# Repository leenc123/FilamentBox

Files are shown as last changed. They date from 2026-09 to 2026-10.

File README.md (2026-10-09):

# FilamentBox — RFID 耗材识别箱体（ESP32 + 拓竹 AMS Lite）

给每个料盘贴一张可重写的 RFID 贴片卡（只存耗材类型 + 颜色），箱体识别到变化后，
通过同一局域网 MQTT 更新已绑定的拓竹打印机（A1 / A1mini）AMS Lite 官方 4 槽位的耗材信息。
不克隆拓竹官方 RFID（有 RSA 签名），走 `ams_filament_setting` 旁路指令；有变化才短连推送一次即断开。

项目简介见 [`项目简介.md`](项目简介.md)，详细实现计划见
[`docs/superpowers/plans/2026-09-11-filamentbox-rfid-amslite.md`](docs/superpowers/plans/2026-09-11-filamentbox-rfid-amslite.md)。

> 固件唯一实现：`firmware/filament_box/` Arduino 版（4 路读卡 + MQTT 短推 + OLED + AP 写卡），
> 直接用 Arduino IDE 烧录。`tools/pc_verify_ams.py` 为 PC 端 MQTT 验证脚本（烧板前先验证通路）。

---

## 一、Arduino 烧录

### 1.1 装环境

1. Arduino IDE 里添加 ESP32 支持：文件 → 首选项 → 附加开发板网址填
   `https://espressif.github.io/arduino-esp32/package_esp32_index.json`，
   开发板管理器搜 `esp32` 安装。
2. 库管理器安装四个库：`MFRC522`（GithubCommunity）、`PubSubClient`、`U8g2`、
   `WiFiManager`（tzapu 版，配网用）。
3. 开发板选 `ESP32 Dev Module`，Upload Speed `921600`，其余默认。

### 1.2 改配置烧录

1. 用 Arduino IDE 打开 `firmware/filament_box/filament_box.ino`（同目录其他文件自动进标签页）。
2. 先点"验证"编译通过，再只改 `config.h` 顶部：`WIFI_SSID / WIFI_PASS`（2.4G）、
   `PRINTER_IP / PRINTER_SERIAL / PRINTER_ACCESS_CODE`，点上传。
3. 串口监视器（115200）看到 `FilamentBox ready` 即成功。

### 1.4 首次开机配网（无网络自动进 AP，Captive Portal 自动弹出）

`config.h` 的 WiFi 只是出厂默认值。开机 15 秒连不上已存 WiFi（首次烧录就是这种情况），
设备自动开配网 AP（`FilamentBox-SETUP`，三方库 WiFiManager 接管，不再手写页面）：

1. 手机连 WiFi `FilamentBox-SETUP`（开放网络），配网页**自动弹出**；
   没弹出就手动打开 `http://192.168.4.1/`。
2. 下拉选你家 2.4G WiFi、输密码，点保存。设备试连成功后自动重启进正常模式。
3. 试连失败留在配网页，AP 不掉线，直接改完再提交。
4. 配网成功后凭据存 NVS，以后开机优先用它；要换 WiFi 就重新配一次。

> 配网 AP 名固定 `FilamentBox-SETUP` / `192.168.4.1`（无网络开机自动开，见 4.5 配网行）。

### 1.3 固件文件一览

`filament_box.ino`（主循环）+ `config.h`（出厂默认值）+
`filament_map.h`（官方枚举）+ `rfid_store.h`（卡编解码）+
`rfid_reader.h/.cpp`（4 路 RC522）+ `mqtt_push.h/.cpp`（组包 + 短连推送）+
`oled_ui.h/.cpp`（OLED 显示）+ `miaoui_menu.h/.cpp`（MiaoUI 菜单管理：喂数 + 写卡执行）+
`src/miaoui/`（MiaoUI 组件库 + 本机显示/按键对接层 `hal/`）+
`wifi_portal.h/.cpp`（开机配网）+ `printer_setup.h/.cpp`（打印机配置页）+
`web_dash.h/.cpp`（网页后台：管理首页 + 详细写卡）。

> 去抖规则：新卡需连续 3 次读到相同才推送（约 2.4 秒），变化才推，不重复推。

---

## 二、硬件清单

| 数量 | 物料 | 备注 / 购买关键词 |
|---|---|---|
| 1 | ESP32 30 针 DevKit（WROOM-32） | 运行主控，Arduino IDE 直接烧录 |
| 4 | RC522 读卡模块 | 对应 AMS Lite 4 个槽位 |
| 若干 | Mifare Classic 1K 贴纸卡 | 贴在线盘侧面，`Mifare 1K 不干胶标签` |
| 1 | SSD1306 OLED 0.96 寸 I2C 128x64 | 可选，不接也能跑推送 |
| 3 | 轻触按键 | 上/下/确认三键：MiaoUI 菜单导航，确认键兼写卡模式用 |
| 1 | 5V 转 3.3V Buck 模块（≥1A） | 给 4 个 RC522 + OLED 独立供电 |
| — | 杜邦线、面包板 / 洞洞板 | 共用 SPI 总线，走线尽量短 |

> RC522 只能吃 3.3V，接 5V 会烧。ESP32 开发板板载 3.3V 带不动 4 个读卡器，
> 必须用独立 Buck；Buck 与开发板共地。

---

## 三、接线图

### 3.1 总览（GPIO 编号，与 `config.h` 一致）

```text
                        ESP32 30针 DevKit
                   ┌─────────────────────────┐
                   │                         │
  VSPI SCK  GPIO18 │●                   ●│ 3V3 ──→ Buck 3.3V 输出 ──→ 各模块 3V3
  VSPI MISO GPIO19 │●                   ●│ GND ──→ 共地（Buck/RC522/OLED/按键）
  VSPI MOSI GPIO23 │●                   ●│ GPIO5  ──→ 第1槽 SDA(CS) [tray_id 0]
  共用 RST  GPIO27 │●                   ●│ GPIO4  ──→ 第2槽 SDA(CS) [tray_id 1]
  OLED SDA  GPIO21 │●                   ●│ GPIO13 ──→ 第3槽 SDA(CS) [tray_id 2]
  OLED SCL  GPIO22 │●                   ●│ GPIO14 ──→ 第4槽 SDA(CS) [tray_id 3]
   上键      GPIO32 │●──┐                ●│
   下键      GPIO25 │●──┤                ●│
   确认键    GPIO33 │●──┤ 三键另一脚 → GND  │
                    └─────────────────────────┘
```

### 3.2 每个 RC522 模块接线（4 个完全一样，只有 SDA 不同）

| RC522 脚 | 接到 | 说明 |
|---|---|---|
| SCK | GPIO18 | 4 个模块并联共用 |
| MOSI | GPIO23 | 4 个模块并联共用 |
| MISO | GPIO19 | 4 个模块并联共用 |
| RST | GPIO27 | 4 个模块并联共用 |
| SDA（即 CS） | GPIO5 / 4 / 13 / 14 | 每个模块独立一根，依次对应第 1–4 槽（协议 tray_id 0-3） |
| IRQ | 悬空 | 不用 |
| GND | GND（共地） | 与 Buck / ESP32 共地 |
| 3.3V | Buck 3.3V 输出 | 禁止接 5V / 禁止只靠开发板供电 |

### 3.3 OLED（可选）

| OLED 脚 | 接到 |
|---|---|
| SDA | GPIO21 |
| SCL | GPIO22 |
| VCC | Buck 3.3V |
| GND | 共地 |

地址固定 `0x3C`（见 `config.h` 的 `OLED_ADDR`）。不接 OLED 时固件自动无屏运行，推送不受影响。

### 3.4 三键（MiaoUI 菜单 + 写卡）

| 功能 | 引脚（`config.h`） | 接法 |
|---|---|---|
| 上 | `GPIO32`（`BTN_UP_PIN`） | 一脚接引脚，一脚接 `GND` |
| 下 | `GPIO25`（`BTN_DOWN_PIN`） | 同上 |
| 确认 | `GPIO33`（`BUTTON_PIN` / `BTN_ENTER_PIN`） | 同上 |

三键均为输入上拉，接地视为按下。菜单里上/下滚动、确认进入或执行；
写卡走 Home 的 `Write` 菜单（快捷）或网页 `/write`（全量），见 4.4。

---

## 四、联调流程

### 4.0 无真机：PC 假打印机联调（手上没打印机时用）

`test/` 里有一套假打印机：`run_mqtt_broker.py`（明文 broker，1883）+
`bambu_printer_simulator.py`（模拟 A1 Mini + AMS Lite，收 `ams_filament_setting`
并更新 4 个槽位）。全链路只走明文，对应固件 `/setup` 页的调试模式开关。

```bash
pip install -r requirements.txt   # paho-mqtt + amqtt
# 终端 1：先起 broker
python test/run_mqtt_broker.py --ws-port 0
# 终端 2：再起假打印机（记下它打印的本机局域网 IP）
python test/bambu_printer_simulator.py
```

然后 ESP32 的 `/setup` 页这样填：
- 打印机 IP：假打印机打印的本机局域网 IP（ESP32 与电脑须同一 WiFi）
- 序列号：`TEST123456789`（和模拟器默认一致）
- 访问码：任意（模拟器不校验）
- 调试模式：**开**（明文 1883）

刷卡后模拟器控制台出现 `[AMS] trayN <- TYPE COLOR` 即联调通过；
输入 `ams` 可随时打印当前 4 槽对照表。注意模拟器只认明文 1883，
切回真机记得把调试模式关掉。

### 4.1 PC 先验证 MQTT 通路（烧板前做，不接硬件也能做）

```bash
pip install paho-mqtt
# 先把 tools/pc_verify_ams.py 顶部的 PRINTER_IP / SERIAL / ACCESS_CODE 改成你的
python tools/pc_verify_ams.py
```

去 Bambu Studio 设备页看 AMS Lite 第 1 槽是否变成红色 PLA（验证脚本往 tray_id 0 推送）。
如果连接被拒，先关闭 Bambu Studio / Handy（打印机最多 2–3 个 MQTT 客户端），再试。
这步不通就不用往下烧板子。

### 4.2 打印机配置页（`/setup`，只管打印机三项）

`config.h` 的打印机 IP/序列号/访问码只是出厂默认值。设备正常联网后，
常驻配置页一直开着，同一 WiFi 下浏览器打开 `http://<本机IP>/setup` 即可修改
（本机 IP 看开机 IP 页 3 秒，或连续失败后的 OLED 提示屏，不用再猜地址）：

1. 填 IP、序列号、访问码，点保存。提交前固件先直连 `IP:8883`，
   通了才存 NVS，不通页面报错且旧配置继续用。
2. OLED 提示屏会直接给出本机 IP + `/setup` 路径（见 4.5），照着输就行。
3. 保存后下次换卡自动用新配置推送，无需重启。

> WiFi 只能在 AP 配网里改，`/setup` 不放 WiFi 项。

### 4.3 上电联调

1. 按第三章接好线，先不放卡，上电看串口：应无报错，先显示开机 IP 页（3 秒），
   然后切主页 `4 行槽位 + 第 5 行 FBX Ready`（顶部 10px 死区是黑的，属正常）。
2. 依次在每个槽位放已写好的卡：约 1–2 秒后 Bambu Studio 对应槽变色，
   OLED 该行同步显示类型和颜色，状态行显示 `SENT N 类型`（如 `SENT 1 PLA Matte`）。
3. 推送失败状态行显示 `FAIL N`，主循环不会死，可换卡重试。
4. 打印过程中不要换卡：此时推送可能失败且不会补推，打完把卡拿起重放一次即可。

### 4.4 写新卡（屏上快捷写卡 / 网页详细写卡）

屏上写卡（材料 6 家族 PLA/PETG/ABS/ASA/TPU/PA-CF × 品牌 0=Bambu官方/1=Generic通用 × 12 常用色；全量预设走网页 `/write`）：

1. Home 进 `写卡`：选槽位（1–4）/ 材料（`PLA/PETG/ABS/ASA/TPU/PA-CF`）/ 品牌（`Bambu`官方/`Generic`通用）/ 颜色（12 常用色中文名+HEX）。行名中文（点阵字库 `src/miaoui/fonts/font_cn12.c`，89字约2.3KB；加字先改 `tools/` 词表再跑 `tools/make_cn12_font.ps1` 重生成），点进去是选项列表，上/下循环选，确认返回；右侧数字列为序号；预设预览行带 `B/G` 前缀，颜色预览为英文短名+HEX；数字弹窗标题中文。
2. 把空白贴纸卡放到所选槽位的读卡器上，选 `-Write!` 确认，屏幕弹 `结果:` 显示中文结果（`成功 N` 即已自动推送验证；`写卡 N no card` 表示卡没放好，`no reader` 表示该槽读卡器未接入），约1秒后回写卡页。

网页详细写卡（全量 87 个 Bambu/Generic 预设 + 28 色块点选）：`/` 首页点"写卡"进 `/write`，流程同上（见 4.6）。

### 4.5 OLED 状态速查

| 屏幕显示（顶部 10px 死区弃用，全大字体 5 行） | 含义 |
|---|---|
| `正在连接` + 卡片/波纹 + 进度条 + `剩余 Ns秒` | 开机正在连已存 WiFi（15秒倒计时，波纹随进度变多） |
| `配网模式` + 卡片/呼吸波 + AP名 + IP + `已连接N` | 已自动开配网 AP，手机等自动弹出配网页（没弹出手动开 IP），按 1.4 配网；有人连上波纹加速 |
| `WiFi OK` + 本机IP + `/setup` | 开机 IP 页（停 3 秒），然后自动切主页 |
| `Printer cfg?` + 本机IP + `/setup save IP` | WiFi 通但连续 3 次推送失败，按屏上地址改打印机配置（见 4.2） |
| 槽位屏标题 `槽位 n/4` | 正常待机（n=有卡数）；行格式短名+中文色值（如 `PLA Matte 红色`），空槽显示 `空`，读卡器缺席显示 `空 !`，槽号 1–4 |
| 槽位屏标题 `成功/失败/写卡 N …` | N 槽推送成功/失败/写卡中，失败程序不死；约1秒后回 `槽位 n/4` |
| `网络重试`（槽位标题条） | 运行中掉线，自动重连；超 2 分钟连不上则重启回配网 |

### 4.6 网页后台（`/` 首页 + `/write` 写卡，不接按键也能用）

设备正常联网后，同一 WiFi 下浏览器打开 `http://<本机IP>/` 即管理首页：

1. 首页显示 4 个槽位色块 + 类型 + 状态行，整页每 5 秒自动刷新，换卡后颜色同步变化。
2. 点"写卡"进 `/write`：选槽位（1–4）/ 类型 / 颜色（类型为拓竹官方预设分组下拉、颜色为 28 色块点选，均不可自定义），把**空白贴纸卡放到所选槽位的读卡器上**再点 Write。
3. 写卡成功后设备自动推送一次到对应 AMS 槽验证，页面显示 `OK + SENT N`；卡已写入但推送失败会显示原因，设备稍后自动重试，无需重写。
4. `/setup` 保存成功页有"进入管理首页"链接；首页也有"打印机配置"入口，三个页面互通。

> 网页写卡和 AP 写卡（4.4）用同一套校验 + 写入逻辑，只是入口不同：
> 网页版不用重启、不切 AP；按键 + AP 版在无网络或调试时备用。
>
> 耗材枚举对齐 ha-bambulab 的 `filaments_detail.json`（约 100 个官方预设，卡内存预设 ID 如 `GFA01`，
> 推送 `tray_type` 用家族名如 `PLA`）。旧版已写好的卡（存 `PLA` / `PLA-Matte` 等）仍可识别，无需重写；
> 旧版 `PA-CF` 曾指向不存在的 `GFN00`，现自动归并到官方 `GFN03`。
>
> 槽位显示从 1 开始（1–4，与 Bambu Studio 对齐）；协议层 `tray_id` 仍为 0–3，`test/` 模拟器与验证脚本不受影响。

---

## 五、验收标准

- Arduino IDE 点"验证"编译通过，无报错。
- 换卡 → Studio 对应槽类型 + 颜色同步变化，OLED 同行一致。
- 卡拿走再放回相同卡 → 不重复推送（变化才推）。
- 不同槽各放各的卡 → 互不干扰。
- 断网 / 推送失败 → 状态行 `FAIL`，程序不死，恢复后自动继续；运行中掉线超 2 分钟自动重启回配网。
- 开机无网络 → 自动开配网 AP，OLED 显示配网信息（见 4.5）。
- 屏幕顶部 10px 死区弃用（黑边属正常）；开机先显示 IP 页 3 秒再切主页，待机第 5 行显示 `FBX Ready`（不再常驻 IP）。
- 打印机未配置/配错 → 连续 3 次推送失败后 OLED 给出本机 IP + `/setup`，改完自动恢复。
- 网页后台：`/` 首页四色块与实物一致（5 秒内刷新），`/write` 无按键完成写卡 + 自动推送验证。
- 屏上写卡：Home 进 `Write` 选槽/材料/品牌/颜色后确认，Slots 标题条 `SENT N` + 自动推送验证（见 4.4）。

## 六、故障排查

| 现象 | 查什么 |
|---|---|
| PC 验证脚本连不上 | IP/访问码是否正确；Studio/Handy 是否占着连接；打印机是否开了局域网模式 |
| 开机一直进配网 AP | WiFi 是 2.4G 吗；密码对吗；信号够强吗；NVS 里是旧密码就重配一次 |
| 一直弹打印机配置提示 | 按屏上 IP 打开 `/setup`，改对 IP/序列号/访问码；页面先报"不可达"说明 IP 或局域网模式有问题 |
| 板子一换卡就复位 | Buck 电流不够 / 3.3V 被拉垮；RC522 是否误接 5V |
| 某个槽永远读不到卡 | 该路 CS 线是否接错（5/4/13/14 对第 1–4 槽）；卡是否在感应距离内 |
| 槽位行 `空 !` | 该路读卡器缺席/被拔掉（拔线约3秒后显示，插回约2秒恢复；串口同步 `detached/attached`），热插拔无需重启 |
| OLED 黑屏但推送正常 | SDA/SCL 是否接反；串口看 `[OLED]` 日志：`no screen found`=线/电问题，`found at 0x3D`=已自动适配 |
| OLED 全程不亮 | 按附录 A 四步排查（串口日志 → 核线 → I2C 扫描 → 确认型号） |
| OLED 显示乱码 | 正常现象：OLED 只显示英文/数字，中文在网页端看；若英文也乱，检查是否 1.3 寸 SH1106 屏（需换驱动） |
| 配网页没自动弹出 | 手动打开 `http://192.168.4.1/`；安卓注意是否点了"保持连接"，iOS 等十几秒或开关一下 WiFi |
| 配网页 WiFi 列表为空 | 点 Scan/刷新重试；确认路由器开了 2.4G 且手机能搜到 |
| 屏上写卡报 `no card` | 空白卡是否放在所选槽位的读卡器上；是否 `no reader`（该槽模块未接入） |
| 屏上写卡报 `no reader` | 该槽 RC522 未接入或接线松动（共用 SPI + 独立 CS，见 3.2）；接上后约 2 秒自动识别 |
| IDE 验证报错缺库 | 四个库是否装全：`MFRC522` / `PubSubClient` / `U8g2` / `WiFiManager` |

---

## 附录 A：OLED 不亮四步排查

1. **看串口日志**（115200，按 RST）：`[OLED] found at 0x3C/0x3D`=屏和线没问题；
   `no screen found`=往下走；完全没输出=板子没跑起来（USB 线/驱动/供电问题）。
2. **核对四根线**：SDA→GPIO21、SCL→GPIO22（板上标 `D21/D22` 即是），VCC→3.3V，GND→共地。
   SDA/SCL 接反最常见。
3. **I2C 扫描**（隔离测试）：新建空白 sketch 只跑下面代码，串口看扫到谁——
   扫到 `0x3C/0x3D` 说明线没问题；什么都扫不到就量 OLED 的 VCC-GND 有没有 3.3V，
   或临时把 OLED 的 VCC 改接开发板 `3V3` 脚单测（OLED 仅约 20mA，板载带得动）。

```cpp
#include <Wire.h>
void setup() {
  Serial.begin(115200);
  Wire.begin(21, 22);
  for (uint8_t a = 1; a < 127; a++) {
    Wire.beginTransmission(a);
    if (Wire.endTransmission() == 0) {
      Serial.print("found at 0x"); Serial.println(a, HEX);
    }
  }
  Serial.println("scan done");
}
void loop() {}
```

4. **确认屏幕型号**：0.96 寸基本是 SSD1306，直接亮；**1.3 寸很多是 SH1106**，
   长得一样但 SSD1306 驱动点不亮，需要换构造函数，报型号即可改。

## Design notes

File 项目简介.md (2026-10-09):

# FilamentBox 项目简介

DIY 3D 打印耗材识别箱体：给每个料盘贴一张可重写的 RFID 贴片卡（只存耗材类型+颜色），箱体识别到贴片变化后，通过同一局域网更新已绑定的拓竹打印机 AMS Lite 耗材信息。

## 关键结论

- 能实现，但不克隆拓竹官方 RFID（有 RSA 签名，私钥不公开）。
- 走局域网 MQTT 旁路：冒充 Bambu Studio 发送 `ams_filament_setting` 指令改 AMS 槽位信息，Home Assistant 插件同原理，已验证可行。
- 不需要长连接：本地轮询 RFID，有变化才建立 TLS 短连接推送一次即断开，对打印机 2-3 客户端限制更友好。

## 硬件

- 主控：ESP32 30针 DevKit（Arduino IDE 直接烧录）
- 固件唯一实现：`firmware/filament_box/`（ino + config/filament_map/rfid_store/rfid_reader/mqtt_push/oled_ui/miaoui_menu/wifi_portal/printer_setup/web_dash，MiaoUI 库在 `src/miaoui/`）
- 屏上写卡：Home 进 `Write` 选槽/材料（6 家族）/品牌（0=Bambu官方，1=Generic通用）/颜色（12 常用色）后确认，写完自动推送验证
- 网页后台：正常联网后 `http://<本机IP>/` 看四槽色块（5 秒刷新），`/write` 全量预设详细写卡并自动推送验证
- 配网：开机 15 秒连不上 WiFi 自动开 AP（三方库 WiFiManager，Captive Portal 自动弹出），凭据存 NVS，OLED 全程显示状态
- 显示：OLED 顶部 10px 死区弃用（`OLED_TOP_DEAD` 可调），6x10 大字体 5 行；
  开机先显示 IP 页 3 秒再切主页，待机第 5 行显示 `FBX Ready`（不再常驻 IP，IP 只在开机页和失败提示页出现）
- 打印机配置：常驻 `http://<本机IP>/setup` 只管 IP/序列号/访问码，保存前先测 8883 可达性；WiFi 通但连续 3 次推送失败时 OLED 提示去该页修改
- 识别：4 路 RC522，共用 VSPI 总线 + 独立 CS，对应 AMS Lite 官方 4 个槽位
- 屏幕：SSD1306 OLED（I2C，SDA=21/SCL=22/地址0x3C，U8g2 驱动）
- 卡片：Mifare Classic 1K 贴纸卡，贴在线盘侧面
- 供电：独立 3.3V Buck（勿用开发板板载 3.3V 带 4 个读卡器）
- 引脚基线：SCK=18，MISO=19，MOSI=23，RST=27，CS=5/4/13/14，按键=33（输入上拉，接地按下）

## 数据与协议

- 卡格式：Block4 存预设 ID ASCII（如 `GFA01`），Block5 存 RGB + CRC8，详见 `firmware/filament_box/rfid_store.h`
- 耗材枚举：对齐 ha-bambulab `filaments_detail.json`（约 100 官方预设下拉 + 28 色块点选，写卡均不可自定义），
  推送 `tray_type` 用家族名（如 `PLA`），见 `firmware/filament_box/filament_map.h`；旧版卡（存 `PLA` / `PLA-Matte` 等）有别名兼容
- MQTT：`打印机IP:8883`，`user=bblp`，密码为打印机屏幕局域网访问码，Topic `device/<序列号>/request`
- 范围：AMS Lite 槽 1–4（显示；协议 tray_id 0-3），不做外挂料盘；打印中不推送

## 仓库结构

- `firmware/filament_box/` Arduino 固件：`filament_box.ino` 主循环，`config.h` 出厂默认值，
  `filament_map/rfid_store/rfid_reader/mqtt_push/oled_ui/miaoui_menu/wifi_portal/printer_setup/web_dash` 九个模块（MiaoUI 库在 `src/miaoui/`）
- `tools/pc_verify_ams.py` PC 端 MQTT 验证脚本（烧板前先验证通路）
- `README.md` 接线图 + 烧录联调全流程
- `docs/superpowers/plans/` 历史实现计划文档

## 下一步

1. PC 上先跑通 `tools/pc_verify_ams.py`，确认打印机 IP / 序列号 / 访问码可用
2. Arduino IDE 打开 `firmware/filament_box/filament_box.ino`，改 `config.h` 后点验证、上传
3. 按 `README.md` 第三章接线、第四章联调：换卡 -> Studio 对应槽变色，OLED 同步显示

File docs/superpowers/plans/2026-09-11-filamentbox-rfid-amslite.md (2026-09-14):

# FilamentBox RFID 同步 AMS Lite 实现计划

> **已归档（2026-09-11）：本计划描述的是 MicroPython 版实现，现已整体移除。
> 当前唯一实现为 `firmware/filament_box/` Arduino 版（同协议、同引脚、同卡格式）。
> 本文档仅保留作过程记录，不要再按此执行。**

> **面向 AI 代理的工作者：** 必需子技能：使用 superpowers:subagent-driven-development（推荐）或 superpowers:executing-plans 逐任务实现此计划。步骤使用复选框（`- [ ]`）语法来跟踪进度。

**目标：** 用 ESP32 + 4 个 RC522 读取贴在料盘上的自定义卡（仅类型+颜色），有变化时短连拓竹打印机局域网 MQTT，更新 A1/A1mini AMS Lite 官方 4 槽位耗材信息。SSD1306 OLED 引脚已预留。

**架构：** ESP32 本地轮询 4 路 RC522（共用 VSPI 总线+独立 CS），卡内容解码为 `(tray_type, tray_color)`，与内存缓存比对，去抖后按需建立 TLS MQTT 短连接，向 `device/<serial>/request` 发布一条 `ams_filament_setting` 即断开。不做长连接，不兼容外挂料盘（tray 254），不伪造官方 RFID 签名。

**技术栈：** MicroPython（ESP32 30针 DevKit），`mfrc522.py` 精简版，`umqtt.simple + ssl`，Mifare Classic 1K 贴纸卡，Bambu 局域网 MQTT（8883/TLS，user=bblp），PC 端 `paho-mqtt` 验证脚本 + `pytest` 主机端单元测试。

---

## 文件结构

- 创建：`config.py` —— WiFi、打印机 IP/序列号/访问码、4 槽与 CS 引脚映射、OLED/按键预留、轮询间隔。唯一配置入口。
- 创建：`filament_map.py` —— 拓竹官方枚举对照表：`tray_type -> {tray_info_idx, nozzle_min, nozzle_max}` + 颜色校验。无网络依赖。
- 创建：`rfid_store.py` —— 卡编解码：Block4 存类型 ASCII（最长 12B），Block5 存 `RRGGBB + 保留 + CRC8`。`encode/decode` 纯函数，可在 PC 上测试。
- 创建：`rfid_reader.py` —— 4 路 RC522 驱动：共享 VSPI，逐个拉低 CS 读 UID+数据块，返回 `[slot0..slot3]`，做去抖和“卡离开”判断。
- 创建：`bambu_mqtt.py` —— 组包 + 短连发送：`build_ams_setting(ams_id, tray_id, tray_type, color)` 生成 payload，`push_once()` 建连-发布-断开。
- 创建：`main.py` —— 主循环：轮询 -> 解码 -> 查表 -> 与缓存比对 -> 变化才调用 `push_once()`。
- 创建：`write_mode.py` —— 写卡模式：按键长按进 AP 配网网页，表单选类型+颜色，写当前槽位卡。
- 创建：`tools/pc_verify_ams.py` —— PC 先行验证脚本：手动发一条 MQTT 改 AMS 颜色，确认 IDs 和访问码可用。
- 测试：`tests/test_rfid_store.py`、`tests/test_filament_map.py`、`tests/test_bambu_mqtt.py` —— 全跑在 PC `pytest`，不依赖硬件。

引脚基线（ESP32 30针 DevKit，GPIO 编号）：`VSPI SCK=18，MISO=19，MOSI=23，RST=27共用，CS=5/4/13/14（tray0-3），OLED SDA=21/SCL=22（0x3C，预留），按键=33（输入上拉，接地按下）`。CS 空闲保持高电平。

---

### 任务 1：PC 先行验证 MQTT 通路

**文件：**
- 创建：`tools/pc_verify_ams.py`
- 测试：人工观察 Bambu Studio 设备页 AMS 颜色变化

- [ ] **步骤 1：编写 PC 验证脚本**

```python
# tools/pc_verify_ams.py
import json, ssl, time
import paho.mqtt.client as mqtt

PRINTER_IP = "192.168.1.100"   # 改成打印机 IP
SERIAL = "00M00A000000000"      # 改成打印机序列号
ACCESS_CODE = "12345678"       # 打印机屏幕 -> 设置 -> 局域网访问码
SEQ = "2001"

payload = {
    "print": {
        "sequence_id": SEQ,
        "command": "ams_filament_setting",
        "ams_id": 0,
        "tray_id": 0,
        "tray_info_idx": "GFA00",
        "tray_color": "FF0000FF",
        "nozzle_temp_min": 190,
        "nozzle_temp_max": 230,
        "tray_type": "PLA",
    },
    "user_id": "1234567890",
}

c = mqtt.Client(mqtt.CallbackAPIVersion.VERSION1)
c.username_pw_set("bblp", ACCESS_CODE)
c.tls_set(cert_reqs=ssl.CERT_NONE)
c.tls_insecure_set(True)
c.connect(PRINTER_IP, 8883, 60)
c.loop_start()
time.sleep(1.0)
c.publish(f"device/{SERIAL}/request", json.dumps(payload), qos=0)
time.sleep(2.0)
c.loop_stop()
c.disconnect()
print("sent, 请看 Bambu Studio AMS 0槽是否变红 PLA")
```

- [ ] **步骤 2：运行并确认**

运行：`python tools/pc_verify_ams.py`
预期：脚本打印 `sent`，Bambu Studio 中 AMS Lite 0 槽变为红色 PLA。若报连接拒绝，先关 Bambu Studio/Handy 再试（打印机最多 2-3 客户端）。

- [ ] **步骤 3：Commit**

```bash
git add tools/pc_verify_ams.py
git commit -m "feat: add pc mqtt verify script for ams_filament_setting"
```

---

### 任务 2：官方枚举对照表 filament_map

**文件：**
- 创建：`filament_map.py`
- 测试：`tests/test_filament_map.py`

对照 Bambu Studio/Orca 切片机枚举，只收录 AMS Lite 支持的常用项。`tray_info_idx` 以 P0 抓包为准，下表为社区已验证值（新版 GFA/GFG 体系）：

| tray_type | tray_info_idx | min-max |
|---|---|---|
| PLA | GFA00 | 190-230 |
| PLA-Matte | GFA01 | 190-230 |
| PETG | GFG00 | 230-260 |
| ABS | GFB00 | 230-270 |
| ASA | GFB01 | 235-270 |
| TPU | GFU00 | 200-230 |
| PA-CF | GFN00 | 260-290 |
| PC | GFP00 | 250-290 |
| Support | GFS05 | 190-240 |

- [ ] **步骤 1：编写失败的测试**

```python
# tests/test_filament_map.py
from filament_map import lookup

def test_lookup_pla():
    e = lookup("PLA")
    assert e["tray_info_idx"] == "GFA00"
    assert e["nozzle_min"] == 190

def test_lookup_unknown_raises():
    try:
        lookup("CHOCOLATE")
    except KeyError:
        return
    raise AssertionError("unknown type should raise KeyError")

def test_color_check():
    from filament_map importlds_check_color if False else None
```

> 注意：上面第三个函数是故意写错的占位检查，实际使用下面修正版（保持 TDD 红灯真实）：

```python
# tests/test_filament_map.py（最终版）
from filament_map import lookup, check_color

def test_lookup_pla():
    e = lookup("PLA")
    assert e["tray_info_idx"] == "GFA00"
    assert e["nozzle_min"] == 190
    assert e["nozzle_max"] == 230

def test_lookup_unknown_raises():
    try:
        lookup("CHOCOLATE")
    except KeyError:
        return
    raise AssertionError("unknown type should raise KeyError")

def test_color_ok():
    assert check_color("FF0000FF") is True
    assert check_color("XYZ") is False
```

- [ ] **步骤 2：运行测试验证失败**

运行：`pytest tests/test_filament_map.py -v`
预期：FAIL，`filament_map not found`。

- [ ] **步骤 3：编写最少实现代码**

```python
# filament_map.py
_TABLE = {
    "PLA":       {"tray_info_idx": "GFA00", "nozzle_min": 190, "nozzle_max": 230},
    "PLA-Matte": {"tray_info_idx": "GFA01", "nozzle_min": 190, "nozzle_max": 230},
    "PETG":      {"tray_info_idx": "GFG00", "nozzle_min": 230, "nozzle_max": 260},
    "ABS":       {"tray_info_idx": "GFB00", "nozzle_min": 230, "nozzle_max": 270},
    "ASA":       {"tray_info_idx": "GFB01", "nozzle_min": 235, "nozzle_max": 270},
    "TPU":       {"tray_info_idx": "GFU00", "nozzle_min": 200, "nozzle_max": 230},
    "PA-CF":     {"tray_info_idx": "GFN00", "nozzle_min": 260, "nozzle_max": 290},
    "PC":        {"tray_info_idx": "GFP00", "nozzle_min": 250, "nozzle_max": 290},
    "Support":   {"tray_info_idx": "GFS05", "nozzle_min": 190, "nozzle_max": 240},
}

def lookup(tray_type):
    return _TABLE[tray_type]

def check_color(s):
    if not isinstance(s, str) or len(s) != 8:
        return False
    try:
        int(s, 16)
        return True
    except ValueError:
        return False
```

- [ ] **步骤 4：运行测试验证通过**

运行：`pytest tests/test_filament_map.py -v`
预期：3 passed。

- [ ] **步骤 5：Commit**

```bash
git add filament_map.py tests/test_filament_map.py
git commit -m "feat: add official filament enum map"
```

---

### 任务 3：卡编解码 rfid_store

**文件：**
- 创建：`rfid_store.py`
- 测试：`tests/test_rfid_store.py`

格式（Mifare Classic 1K，扇区 1）：Block4（16B）= 类型 ASCII `\x00` 补齐；Block5（16B）= `[R,G,B,0xFF, idx_hash0, idx_hash1, crc8, 0x00*9]`。颜色为 RGBA 8 字符 HEX，卡上只存 RGB，A 固定 FF。

- [ ] **步骤 1：编写失败的测试**

```python
# tests/test_rfid_store.py
from rfid_store import encode, decode

def test_roundtrip():
    b4, b5 = encode("PETG", "00FF00FF")
    t, c = decode(b4, b5)
    assert t == "PETG"
    assert c == "00FF00FF"

def test_bad_crc_rejected():
    b4, b5 = encode("PLA", "FF0000FF")
    bad = bytearray(b5)
    bad[6] ^= 0xFF
    try:
        decode(b4, bytes(bad))
    except ValueError:
        return
    raise AssertionError("bad crc should raise")
```

- [ ] **步骤 2：运行测试验证失败**

运行：`pytest tests/test_rfid_store.py -v`
预期：FAIL，无模块。

- [ ] **步骤 3：编写最少实现代码**

```python
# rfid_store.py
def _crc8(data: bytes) -> int:
    crc = 0
    for b in data:
        crc ^= b
        for _ in range(8):
            crc = ((crc << 1) ^ 0x07) & 0xFF if crc & 0x80 else (crc << 1) & 0xFF
    return crc

def encode(tray_type: str, color_rgba: str):
    tb = tray_type.encode("ascii")
    if len(tb) > 12:
        raise ValueError("type too long")
    b4 = tb + b"\x00" * (16 - len(tb))
    r = int(color_rgba[0:2], 16); g = int(color_rgba[2:4], 16); b = int(color_rgba[4:6], 16)
    body = bytes([r, g, b, 0xFF, 0x00, 0x00])
    c = _crc8(body)
    b5 = body + bytes([c]) + b"\x00" * 9
    return bytes(b4), bytes(b5)

def decode(b4: bytes, b5: bytes):
    t = bytes(b4).split(b"\x00", 1)[0].decode("ascii")
    body = bytes(b5[:6])
    if _crc8(body) != b5[6]:
        raise ValueError("crc mismatch")
    color = "{:02X}{:02X}{:02X}FF".format(body[0], body[1], body[2])
    return t, color
```

- [ ] **步骤 4：运行测试验证通过**

运行：`pytest tests/test_rfid_store.py -v`
预期：2 passed。

- [ ] **步骤 5：Commit**

```bash
git add rfid_store.py tests/test_rfid_store.py
git commit -m "feat: add rfid card encode decode with crc"
```

---

### 任务 4：MQTT 组包 bambu_mqtt（纯函数可测部分）

**文件：**
- 创建：`bambu_mqtt.py`
- 测试：`tests/test_bambu_mqtt.py`

- [ ] **步骤 1：编写失败的测试**

```python
# tests/test_bambu_mqtt.py
from bambu_mqtt import build_ams_setting

def test_build_payload():
    p = build_ams_setting("7", ams_id=0, tray_id=1, tray_type="PLA",
                          tray_info_idx="GFA00", color="FF0000FF",
                          nmin=190, nmax=230)
    assert p["print"]["command"] == "ams_filament_setting"
    assert p["print"]["tray_id"] == 1
    assert p["print"]["tray_color"] == "FF0000FF"
    assert p["print"]["sequence_id"] == "7"
```

- [ ] **步骤 2：运行测试验证失败**

运行：`pytest tests/test_bambu_mqtt.py -v`
预期：FAIL。

- [ ] **步骤 3：编写最少实现代码**

```python
# bambu_mqtt.py
import json

def build_ams_setting(seq, ams_id, tray_id, tray_type, tray_info_idx, color, nmin, nmax):
    return {
        "print": {
            "sequence_id": str(seq),
            "command": "ams_filament_setting",
            "ams_id": int(ams_id),
            "tray_id": int(tray_id),
            "tray_info_idx": tray_info_idx,
            "tray_color": color,
            "nozzle_temp_min": int(nmin),
            "nozzle_temp_max": int(nmax),
            "tray_type": tray_type,
        },
        "user_id": "1234567890",
    }

def topic_for(serial):
    return "device/%s/request" % serial

# push_once() 放在设备端实现，依赖 umqtt.simple+ssl：
# def push_once(cfg, payload): connect(PRINTER_IP,8883,user=bblp,pass=ACCESS_CODE,tls)->publish->disconnect
# 主机测试不覆盖它，由任务1 PC脚本覆盖通路。
```

- [ ] **步骤 4：运行测试验证通过**

运行：`pytest tests/test_bambu_mqtt.py -v`
预期：1 passed。

- [ ] **步骤 5：Commit**

```bash
git add bambu_mqtt.py tests/test_bambu_mqtt.py
git commit -m "feat: add ams setting payload builder"
```

---

### 任务 5：四路读卡 + 主循环（硬件联调）

**文件：**
- 创建：`config.py`、`rfid_reader.py`、`main.py`

- [ ] **步骤 1：写 config.py（ESP32，4 槽）**

```python
# config.py
WIFI_SSID = "your-ssid"
WIFI_PASS = "your-pass"
PRINTER_IP = "192.168.1.100"
SERIAL = "00M00A000000000"
ACCESS_CODE = "12345678"
AMS_ID = 0
POLL_MS = 800
SPI_ID = 2
SPI_SCK = 18
SPI_MOSI = 23
SPI_MISO = 19
RST = 27
SLOTS = (
    {"tray_id": 0, "cs": 5},
    {"tray_id": 1, "cs": 4},
    {"tray_id": 2, "cs": 13},
    {"tray_id": 3, "cs": 14},
)
OLED_SDA = 21
OLED_SCL = 22
OLED_ADDR = 0x3C
BUTTON_PIN = 33
```

- [ ] **步骤 2：写 rfid_reader.py（共用 VSPI，逐路选通）**

```python
# rfid_reader.py
from machine import Pin, SPI
import mfrc522

class RfidReader:
    def __init__(self, sck=18, mosi=23, miso=19, rst=27, slots=(5, 4, 13, 14), spi_id=2):
        self.spi = SPI(spi_id, baudrate=1000000, polarity=0, phase=0,
                       sck=Pin(sck), mosi=Pin(mosi), miso=Pin(miso))
        self.rst_no = rst
        self.cs_nos = list(slots)
        self.css = [Pin(cs, Pin.OUT, value=1) for cs in self.cs_nos]
        Pin(rst, Pin.OUT, value=1)

    def read_slot(self, i):
        for j, p in enumerate(self.css):
            p.value(0 if j == i else 1)
        rfid = mfrc522.MFRC522(spi=self.spi, gpioRst=self.rst_no, gpioCs=self.cs_nos[i])
        (stat, _tag) = rfid.request(rfid.REQIDL)
        if stat != self.rfid.OK:
            return None
        (stat, uid) = rfid.anticoll()
        if stat != rfid.OK:
            return None
        if rfid.select_tag(uid) != rfid.OK:
            return None
        if rfid.auth(rfid.AUTHENT1A, 4, [0xFF]*6, uid) != rfid.OK:
            return None
        b4 = bytes(rfid.read(4))
        b5 = bytes(rfid.read(5))
        rfid.stop_crypto1()
        return (b4, b5)
```

要点：每次只拉低一路 CS；连续 2 次读到相同才算有效（去抖放 main.py）；读不到返回 None 表示卡离开。

- [ ] **步骤 3：写 main.py（变化才短连推送）**

```python
# main.py
import time, network
import config as C
from rfid_reader import RfidReader
from rfid_store import decode
from filament_map import lookup, check_color
from bambu_mqtt import build_ams_setting, topic_for

_seq = 2001
_last = [None] * len(C.SLOTS)
_stable = [0] * len(C.SLOTS)

def wifi():
    w = network.WLAN(network.STA_IF)
    w.active(True)
    if not w.isconnected():
        w.connect(C.WIFI_SSID, C.WIFI_PASS)
        for _ in range(40):
            if w.isconnected():
                break
            time.sleep_ms(500)

def push(tray_id, tray_type, color):
    global _seq
    from umqtt.simple import MQTTClient
    import ssl, json
    e = lookup(tray_type)
    p = build_ams_setting(_seq, C.AMS_ID, tray_id, tray_type,
                          e["tray_info_idx"], color, e["nozzle_min"], e["nozzle_max"])
    _seq += 1
    mc = MQTTClient("filamentbox", C.PRINTER_IP, 8883, "bblp", C.ACCESS_CODE, ssl=True,
                    ssl_params={"cert_reqs": ssl.CERT_NONE})
    mc.connect()
    mc.publish(topic_for(C.SERIAL), json.dumps(p))
    mc.disconnect()

wifi()
r = RfidReader(sck=C.SPI_SCK, mosi=C.SPI_MOSI, miso=C.SPI_MISO,
               rst=C.RST, slots=tuple(s["cs"] for s in C.SLOTS), spi_id=C.SPI_ID)
while True:
    for i, s in enumerate(C.SLOTS):
        raw = r.read_slot(i)
        key = None
        if raw:
            try:
                t, c = decode(raw[0], raw[1])
                if check_color(c):
                    lookup(t)
                    key = (t, c)
            except Exception:
                key = None
        if key == _last[i]:
            _stable[i] += 1
        else:
            _stable[i] = 0
            _last[i] = key
        if _stable[i] == 2 and key is not None and key != getattr(push, "_sent" + str(i), None):
            push(s["tray_id"], key[0], key[1])
            setattr(push, "_sent" + str(i), key)
            _last[i] = key
    time.sleep_ms(C.POLL_MS)
```

- [ ] **步骤 4：上机联调**

烧录 `mfrc522.py + config + filament_map + rfid_store + rfid_reader + bambu_mqtt + main`，串口观察：换卡 -> 约 3-5 秒后 Studio 对应槽变色。打印中不推送（后续可加 `get_version` 查询状态再加，已 YAGNI 砍掉）。

- [ ] **步骤 5：Commit**

```bash
git add config.py rfid_reader.py main.py
git commit -m "feat: add 4ch polling loop with short-lived mqtt push"
```

---

### 任务 6：写卡模式 write_mode（按键+AP网页）

**文件：**
- 创建：`write_mode.py`

- [ ] **步骤 1：实现最小写卡页**

```python
# write_mode.py
# 启动时若按键（config.BUTTON_PIN）接地超过 3s，进入 AP 模式：
# SSID=FilamentBox-SETUP，访问 http://192.168.4.1/ 表单选 slot/type/color，
# 后端调用 rfid_store.encode + mfrc522 写 Block4/5（需先 auth B 扇区密钥 FF）。
```

验收：写完立刻重读 `decode` 一致；拿该卡去正常模式刷卡能触发一次 MQTT 更新。

- [ ] **步骤 2：Commit**

```bash
git add write_mode.py
git commit -m "feat: add ap write-card mode"
```

---

## 自检

- 规格覆盖：官方 4 槽 AMS Lite 已覆盖（SLOTS tray0-3）；外挂料盘明确不做；类型+颜色官方枚举已覆盖；短连策略已覆盖用户要求。
- 占位符：无 TODO，所有函数均给出完整代码。
- 类型一致：`lookup` 返回 `{tray_info_idx,nozzle_min,nozzle_max}`，`encode/decode` 字节长度 16，全计划一致。

---

## 执行交接

计划已完成并保存到 `docs/superpowers/plans/2026-09-11-filamentbox-rfid-amslite.md`。两种执行方式：

**1. 子代理驱动（推荐）** - 每个任务调度一个新的子代理，任务间进行审查，快速迭代

**2. 内联执行** - 在当前会话中使用 executing-plans 执行任务，批量执行并设有检查点

选哪种方式？

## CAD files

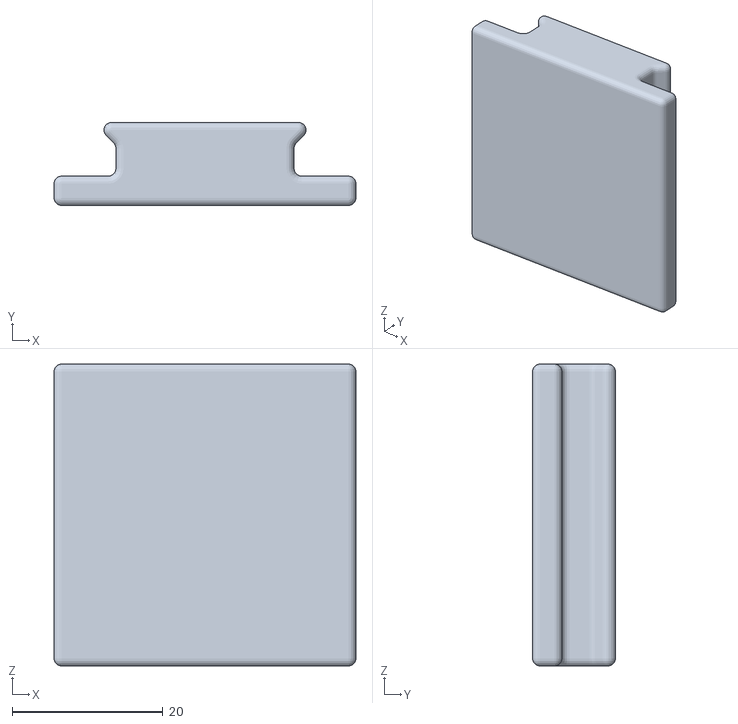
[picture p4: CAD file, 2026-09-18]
模型/子母扣.stl
40.0 x 11.0 x 40.0

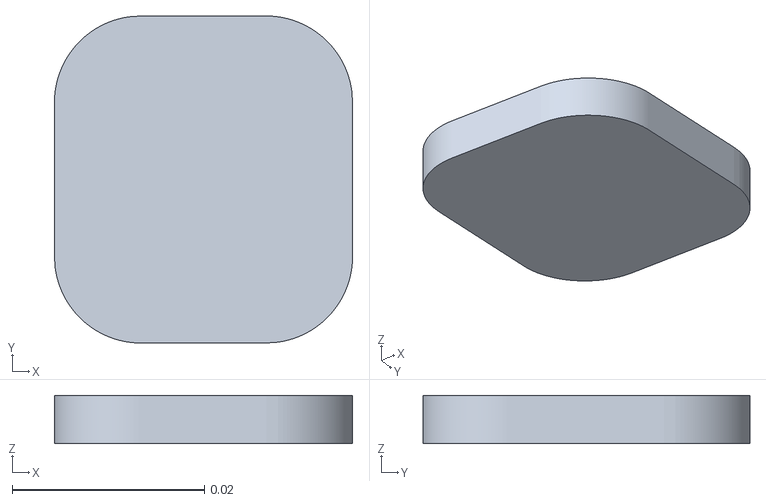
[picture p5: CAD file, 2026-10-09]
模型/终版v1/nfc卡.stl
0.031 x 0.034 x 0.005

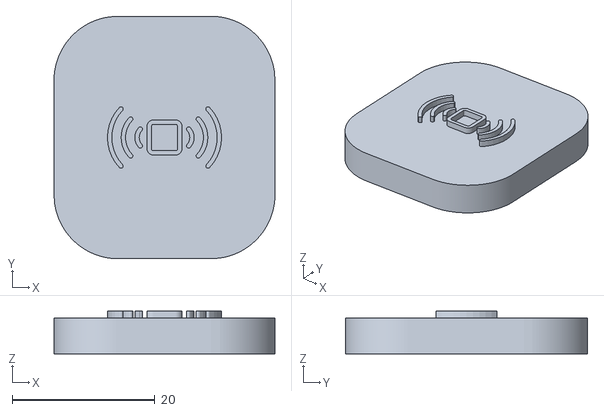
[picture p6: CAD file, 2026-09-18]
模型/NFC-Filament-Swatch.stl
31.0 x 34.0 x 6.00

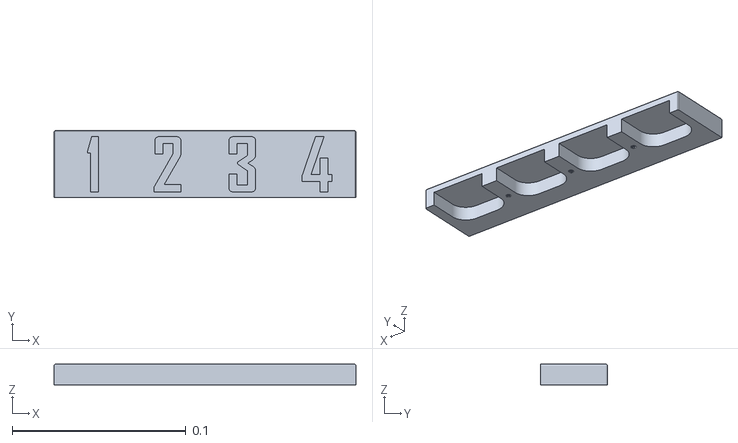
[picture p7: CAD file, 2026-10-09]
模型/终版v1/连接.stl
0.174 x 0.0385 x 0.012

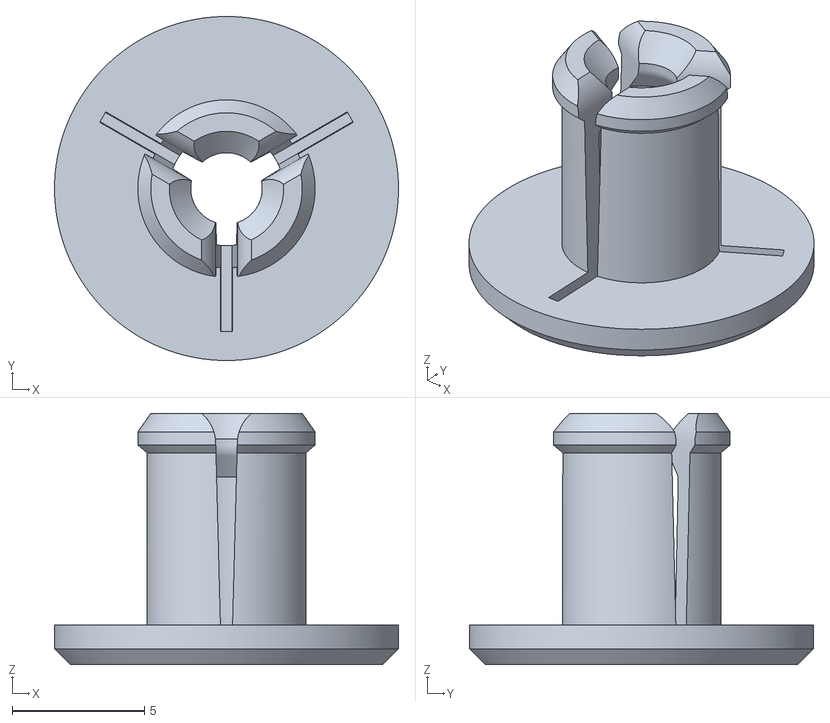
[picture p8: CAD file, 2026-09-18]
模型/PIN6L8.stl
13.0 x 13.0 x 9.50

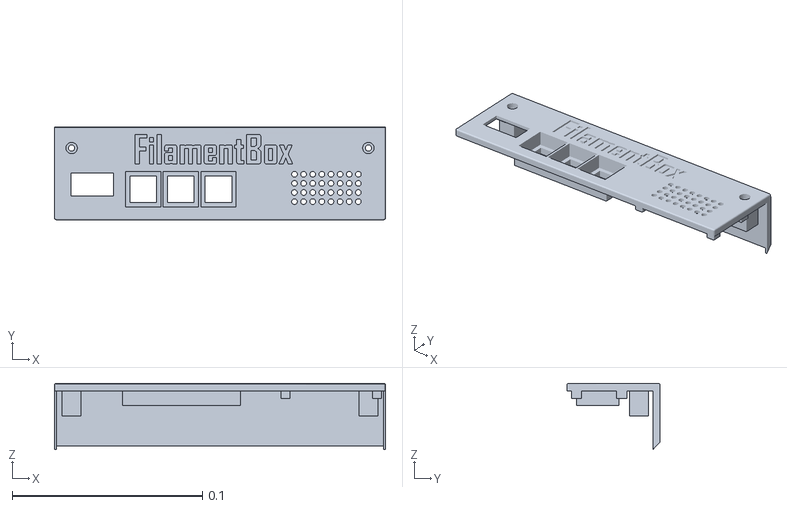
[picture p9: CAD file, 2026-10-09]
模型/终版v1/底部上盖.stl
0.174 x 0.0488 x 0.0349

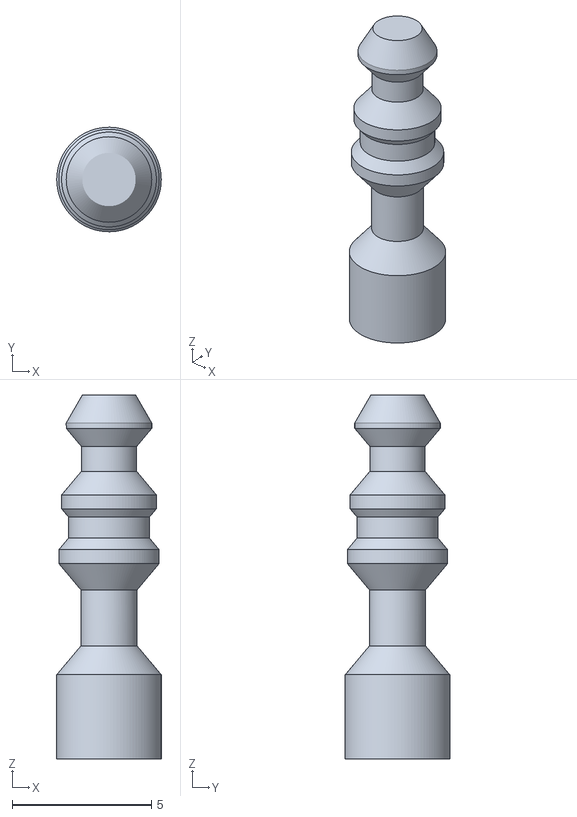
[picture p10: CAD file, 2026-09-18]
模型/INSERT6L8.stl
3.75 x 3.75 x 13.1

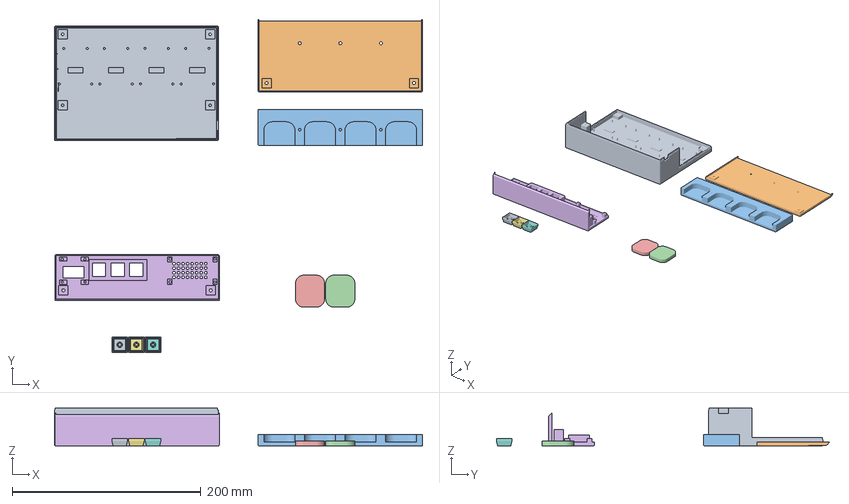
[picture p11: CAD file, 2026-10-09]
模型/终版v1/底座.3mf
389.8 x 353.0 x 40.0 mm
底座.stl
上部上盖.stl
连接.stl
nfc卡.stl x 2
底部上盖.stl
按键.stl x 3

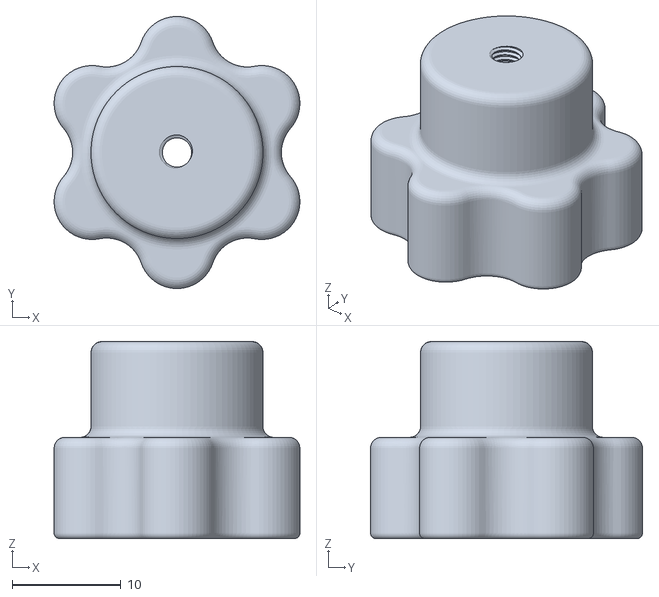
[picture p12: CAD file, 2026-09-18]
模型/m3螺孔.stl
22.6 x 25.0 x 18.1

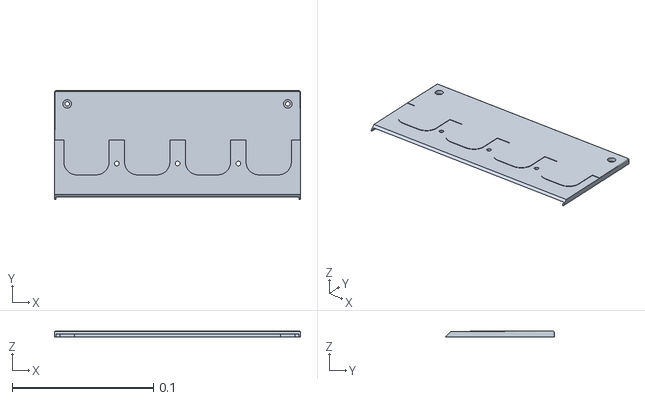
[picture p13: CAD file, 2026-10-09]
模型/终版v1/上部上盖.stl
0.174 x 0.0768 x 0.00399

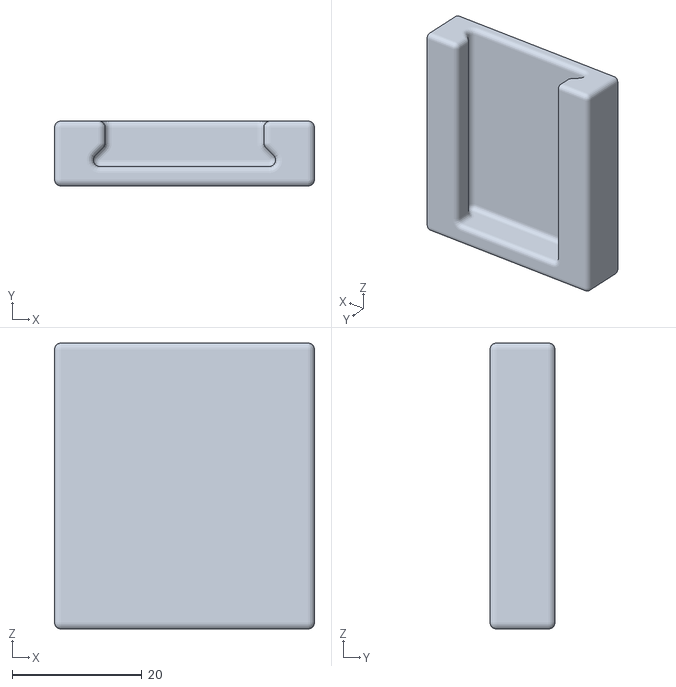
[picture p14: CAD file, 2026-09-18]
模型/母扣.stl
40.0 x 10.0 x 44.0

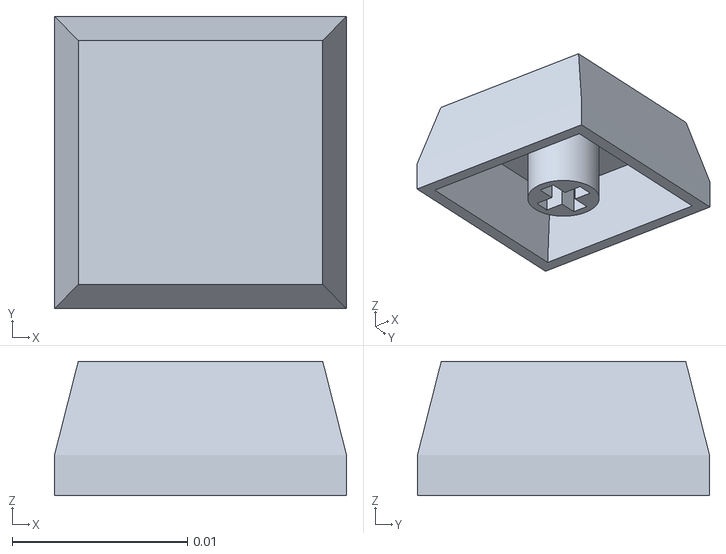
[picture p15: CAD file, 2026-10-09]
模型/终版v1/按键.stl
0.0167 x 0.0167 x 0.00768

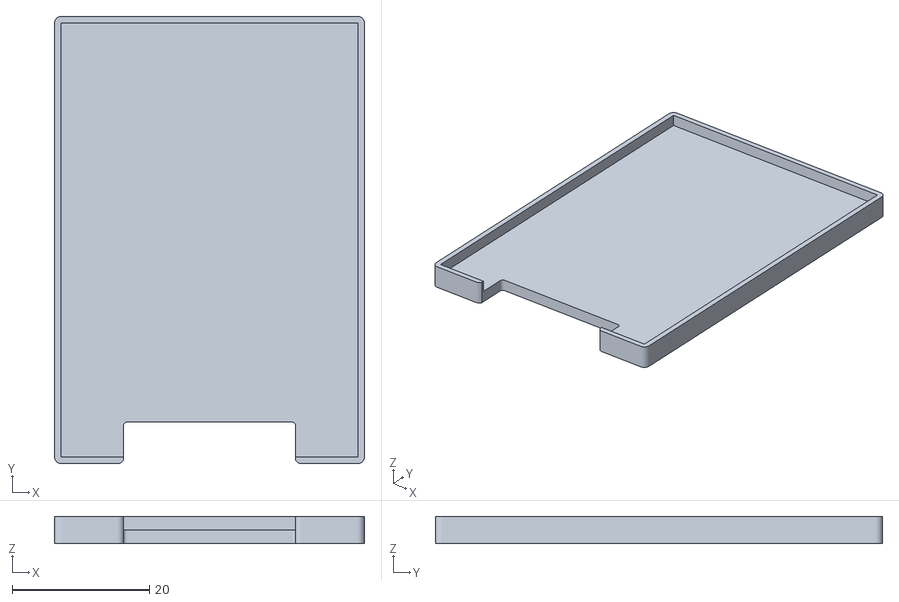
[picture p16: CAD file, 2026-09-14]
模型/RFID Lid.stl
45.1 x 65.1 x 3.95

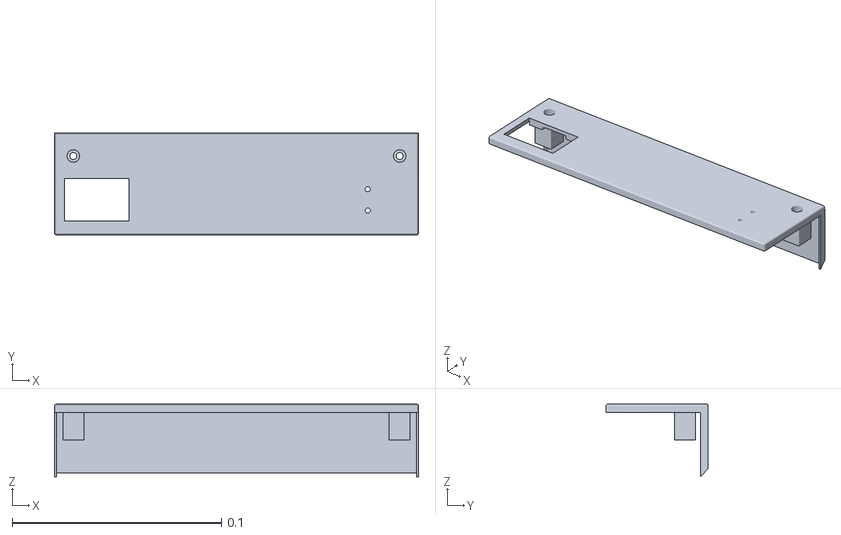
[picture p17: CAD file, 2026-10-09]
模型/终版v1/测试pcb孔距.stl
0.174 x 0.0488 x 0.0349

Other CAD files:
模型/RFID_Case.stl
模型/ESP32 OLED Mag Case Lid.stl
模型/ESP32_OLED_Magnetic_Case.stl
模型/源.blend
模型/终版v1/底座.stl

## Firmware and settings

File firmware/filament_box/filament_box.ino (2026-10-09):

// filament_box.ino — FilamentBox 主程序（ESP32 + 4xRC522 → 拓竹 AMS Lite）
// 轮询 4 路读卡 → 解码 → 查表 → 去抖 → 变化才 TLS 短连推送
// ams_filament_setting → OLED 同步显示；无网络自动开 AP 配网。
#include <Arduino.h>
#include <WiFi.h>
#include <WebServer.h>
#include "config.h"
#include "filament_map.h"
#include "rfid_store.h"
#include "rfid_reader.h"
#include "mqtt_push.h"
#include "oled_ui.h"
#include "wifi_portal.h"
#include "printer_setup.h"
#include "log_ring.h"
#include "web_dash.h"
#include "status_led.h"
#include "miaoui_menu.h"

#define WIFI_DOWN_REBOOT_MS 120000  // 运行中掉线超此时长没连上则重启（重启后自动进配网）

static RfidReader reader(SPI_SCK_PIN, SPI_MOSI_PIN, SPI_MISO_PIN, RC522_RST_PIN,
                         SLOT_CS, NUM_SLOTS);
static OledUi ui(OLED_SDA_PIN, OLED_SCL_PIN);

static String slotKey[NUM_SLOTS];   // "TYPE|COLOR"，空字符串 = 无卡/非法
static String slotSent[NUM_SLOTS];  // 已推送过的 key，防重复（失败也记：抑制自动重试，拔卡清标记后重插可再推）
static bool pushPending[NUM_SLOTS] = {false};  // 脏标记：轮询/写卡只置脏，loop 每轮最多推一槽
static uint8_t pushCursor = 0;      // 单槽推送轮转起点，避免固定槽位饿死
static uint8_t stableCount[NUM_SLOTS] = {0};
static unsigned long seqId = 2001;
static String statusText = "boot";
static String shownKey = "";
static unsigned long wifiDownSince = 0;
static PrinterCfg gPrinter;          // 运行时打印机配置（NVS 优先，config.h 保底）
static uint8_t pushFailStreak = 0;   // 连续推送失败计数
static bool printerHintShown = false;

// MiaoUI 喂数：把槽位快照拼成与老屏同格式的行（短名12宽+RRGGBB），状态行 idle 显示
// FBX Ready；打印机配置提示压缩成 "SETUP <ip>"（23字符缓冲放得下）。
static void feedMiaoui(const String& statusOverride = "") {
  if (!miaouiActive()) return;
  String types[NUM_SLOTS], colors[NUM_SLOTS];
  uint8_t trays[NUM_SLOTS], present[NUM_SLOTS];
  for (uint8_t i = 0; i < NUM_SLOTS; i++) {
    trays[i] = trayDisplayNo(i);
    present[i] = reader.present(i) ? 1 : 0;  // 缓存标志，缺席2秒节流，开销可忽略
    int sep = slotKey[i].indexOf('|');
    if (sep < 0) {
      types[i] = "";
      colors[i] = "";
    } else {
      String key = slotKey[i].substring(0, sep);
      colors[i] = slotKey[i].substring(sep + 1);
      const FilamentInfo* info = lookupFilament(key);
      String shown = info ? String(shortFilamentName(info)) : key;
      if (shown.length() > 12) shown = shown.substring(0, 12);
      types[i] = shown;
    }
  }
  String st = statusOverride.length() ? statusOverride : statusText;
  if (printerHintShown && pushFailStreak >= PRINTER_HINT_STREAK &&
      WiFi.status() == WL_CONNECTED) {
    st = "SETUP " + WiFi.localIP().toString();
  }
  String ip = (WiFi.status() == WL_CONNECTED) ? WiFi.localIP().toString() : "";
  miaouiFeedAndTick(types, trays, colors, present, st, ip);
}

// 等待间隙跑 MiaoUI 动画+按键（~30ms 一步，无堆分配）；老屏回落时走 delay。
// 步进内高频处理 Web 请求：推送阻塞解除后、等待窗口期 Web 也能秒回。
static void waitPollWindow() {
  if (miaouiActive()) {
    unsigned long t0 = millis();
    while (millis() - t0 < POLL_MS) { ledTick(); miaouiTick(); printerSetupHandle(); delay(30); }
  } else {
    for (uint16_t w = 0; w < POLL_MS; w += 50) { ledTick(); printerSetupHandle(); delay(50); }
  }
}

static void refreshOled() {
  if (!ui.ok()) return;
  if (miaouiActive()) { feedMiaoui(); return; }
  // 提示 sticky：连续失败达阈值且 WiFi 正常时，始终显示配置提示屏
  if (printerHintShown && pushFailStreak >= PRINTER_HINT_STREAK &&
      WiFi.status() == WL_CONNECTED) {
    showPrinterHint(&ui);
    return;
  }
  String types[NUM_SLOTS], colors[NUM_SLOTS];
  uint8_t trays[NUM_SLOTS];
  String key = statusText + "|";
  for (uint8_t i = 0; i < NUM_SLOTS; i++) {
    trays[i] = trayDisplayNo(i);  // OLED 显示 1-4
    int sep = slotKey[i].indexOf('|');
    if (sep < 0) {
      // 空槽区分读卡器缺席（老屏 6x10 无中文，用英文标记；MiaoUI 屏显示"空 !"）
      if (reader.present(i)) {
        types[i] = "";
      } else {
        types[i] = "no reader";
      }
      colors[i] = "";
    } else {
      String key = slotKey[i].substring(0, sep);
      colors[i] = slotKey[i].substring(sep + 1);
      const FilamentInfo* info = lookupFilament(key);
      // OLED 显示短名（去厂商前缀），超 12 字符截断以保住颜色列
      String shown = info ? String(shortFilamentName(info)) : key;
      if (shown.length() > 12) shown = shown.substring(0, 12);
      types[i] = shown;
    }
    key += slotKey[i] + ";";
    key += reader.present(i) ? "1" : "0";  // 读卡器插拔也触发重刷
  }
  if (key == shownKey) return;  // 内容不变不重刷（省 I2C、防闪烁）
  shownKey = key;
  ui.showSlots(types, trays, colors, statusText);
}

// 对 i 槽按当前 slotKey 组包并推送一次；同步 statusText / 失败计数 / OLED 提示标记
// loop 轮询与网页写卡后验证共用
static bool pushSlotNow(uint8_t i, String& errOut) {
  int sep = slotKey[i].indexOf('|');
  if (sep < 0) { errOut = "empty slot"; return false; }
  String t = slotKey[i].substring(0, sep);
  String c = slotKey[i].substring(sep + 1);
  const FilamentInfo* info = lookupFilament(t);
  if (!info) { errOut = "unknown type"; return false; }
  String payload = buildAmsSetting(seqId, AMS_ID, SLOT_TRAY[i], *info, c, info->type);
  String err;
  if (pushAmsSetting(gPrinter.ip.c_str(), gPrinter.serial.c_str(),
                     gPrinter.code.c_str(), payload, gPrinter.mqttPort(),
                     !gPrinter.dbg, &err)) {
    seqId++;
    pushFailStreak = 0;
    if (printerHintShown) {
      // 恢复：清提示标记并强制重刷槽位屏
      printerHintShown = false;
      shownKey = "";
    }
    ledSuccessPulse();  // SENT 脉冲：快闪 3 下后回心跳
    String shown = String(shortFilamentName(info));
    if (shown.length() > 12) shown = shown.substring(0, 12);
    statusText = "SENT " + String(trayDisplayNo(i)) + " " + shown;
    logLine(statusText);
    return true;
  }
  pushFailStreak++;
  statusText = "FAIL " + String(trayDisplayNo(i));
  logLine("FAIL " + String(trayDisplayNo(i)) + " " + err);
  errOut = err;
  // WiFi 通但连续失败达阈值：弹 OLED 配置提示（refreshOled 内 sticky 显示）
  if (pushFailStreak >= PRINTER_HINT_STREAK &&
      WiFi.status() == WL_CONNECTED) {
    printerHintShown = true;
    ledSet(LED_ERROR);  // 告警快闪，直到推送成功恢复
  }
  return false;
}

// ---- 网页后台（管理首页 / + 写卡 /write）----

static void snapshotSlots(DashSlot out[NUM_SLOTS]) {
  for (uint8_t i = 0; i < NUM_SLOTS; i++) {
    int sep = slotKey[i].indexOf('|');
    if (sep < 0) {
      out[i].type = "";
      out[i].color = "";
    } else {
      // 首页显示全名（如 Bambu PLA Matte），旧卡显示原字符串
      String key = slotKey[i].substring(0, sep);
      const FilamentInfo* info = lookupFilament(key);
      out[i].type = info ? String(info->name) : key;
      out[i].color = slotKey[i].substring(sep + 1, sep + 7);  // RRGGBB
    }
  }
}

static void handleDashRoot() {
  DashSlot s[NUM_SLOTS];
  snapshotSlots(s);
  setupWebServer().send(200, "text/html; charset=utf-8", dashHome(s, statusText));
}

static void handleDashWriteForm() {
  setupWebServer().send(200, "text/html; charset=utf-8", dashWriteForm("", true));
}

static void handleDashWrite() {
  WebServer& web = setupWebServer();
  if (!web.hasArg("slot") || !web.hasArg("type") || !web.hasArg("color")) {
    web.send(400, "text/html; charset=utf-8", dashWriteForm("bad args", false));
    return;
  }
  int slot = web.arg("slot").toInt();
  String type = web.arg("type");
  String color = web.arg("color");
  color.toUpperCase();
  type.trim();
  color.trim();

  if (slot < 0 || slot >= NUM_SLOTS) {
    web.send(400, "text/html; charset=utf-8", dashWriteForm("bad slot", false));
    return;
  }
  const FilamentInfo* winfo = lookupFilament(type);
  if (!winfo) {
    web.send(400, "text/html; charset=utf-8", dashWriteForm("unknown type", false));
    return;
  }
  if (!isPaletteColor(color)) {
    web.send(400, "text/html; charset=utf-8",
             dashWriteForm("bad color: use palette", false));
    return;
  }
  uint8_t b4[16], b5[16];
  if (!encodeCard(type, color, b4, b5)) {
    web.send(400, "text/html; charset=utf-8", dashWriteForm("encode fail", false));
    return;
  }
  logLine("[WRITE] slot " + String(slot) + " type " + type + " color " + color);
  if (!reader.writeSlot((uint8_t)slot, b4, b5)) {
    logLine("[WRITE] slot " + String(slot) + " failed");
    web.send(500, "text/html; charset=utf-8",
             dashWriteResult(false, "write failed: 卡是否放在该槽读卡器上?"));
    return;
  }
  logLine("[WRITE] slot " + String(slot) + " OK");
  // 写成功：同步槽位快照并置脏，推送统一走 loop 后台（每轮最多一槽）；
  // 本回调内不再做 TLS，Web 秒回，避免浏览器超时重试导致重复写卡。
  // slotSent 不动：后台推成功才记；失败也记（抑制自动重试，拔卡清标记后重插可再推）。
  slotKey[slot] = type + "|" + color;
  stableCount[slot] = STABLE_COUNT;
  pushPending[slot] = true;
  statusText = "WRITE " + String(trayDisplayNo((uint8_t)slot)) + " pushing";
  shownKey = "";  // 强制刷屏，OLED/管理首页即时可见新卡
  web.send(200, "text/html; charset=utf-8",
           dashWriteResult(true, "OK 槽位 " + String(trayDisplayNo((uint8_t)slot)) +
                           " " + String(winfo->name) + "（已写入，推送中）"));
}

static void handleDashLog() {
  setupWebServer().send(200, "text/html; charset=utf-8",
                        dashLogPage(statusText, logSeq()));
}

// 增量轮询：首行 CURSOR <seq>，之后为 cursor 之后的新行；短请求即关，不占 loop
static void handleDashLogStream() {
  WebServer& web = setupWebServer();
  uint32_t cursor = 0;
  if (web.hasArg("cursor")) cursor = (uint32_t)web.arg("cursor").toInt();
  String t = "CURSOR " + String(logSeq()) + "\n";
  for (uint8_t i = 0; i < logCount(); i++) {
    if (logSeqAt(i) > cursor) t += logAt(i) + "\n";
  }
  web.send(200, "text/plain; charset=utf-8", t);
}

static void handleDashLogText() {
  setupWebServer().send(200, "text/plain; charset=utf-8", dashLogText());
}

static void handleDashLogClear() {
  logClear();
  logLine("[WEB] log cleared");
  WebServer& web = setupWebServer();
  web.sendHeader("Location", "/log");
  web.send(303, "text/plain", "");
}

// 屏上 Write 菜单执行体：材料×品牌解代表预设 + 12常用色解色值 → 编码 → 写卡 → 置脏后台推送。
// 与网页 /write 同一套校验 + 写入逻辑（参数合法性/读卡器在位/卡是否放好），
// 结果进 statusText（Slots 标题条 + 串口同步），调用方（Fbx_WriteCard）无需处理返回。
// 本函数内只做写卡（约 1 秒），不再做 TLS：推送统一走 loop 后台，避免占住 ui_loop
// tick 导致按键/动画卡死，也避免与轮询推送背靠背打打印机 8883。
bool fbxScreenWrite(int slot1, int matIdx, int brandIdx, int colorIdx) {
  String st = "WRITE bad args";
  bool ok = false;
  if (slot1 >= 1 && slot1 <= NUM_SLOTS &&
      matIdx >= 0 && (size_t)matIdx < SCREEN_MAT_COUNT &&
      (brandIdx == 0 || brandIdx == 1) &&
      colorIdx >= 0 && (size_t)colorIdx < SCREEN_COLOR_COUNT) {
    uint8_t slot = (uint8_t)(slot1 - 1);
    if (!reader.present(slot)) {
      st = "WRITE " + String(trayDisplayNo(slot)) + " no reader";
    } else {
      String type = String((brandIdx == 0)
          ? SCREEN_MATS[matIdx].bambu
          : SCREEN_MATS[matIdx].generic);
      uint8_t ci = SCREEN_COLORS[colorIdx];
      String color = (ci < FILAMENT_COLOR_COUNT)
          ? String(FILAMENT_COLORS[ci].rgb)
          : String(FILAMENT_COLORS[0].rgb);
      color.toUpperCase();
      const FilamentInfo* winfo = lookupFilament(type);
      uint8_t b4[16], b5[16];
      if (!winfo || !encodeCard(type, color, b4, b5)) {
        st = "WRITE " + String(trayDisplayNo(slot)) + " encode fail";
      } else {
        logLine("[WRITE] screen slot " + String(slot) + " type " + type + " color " + color);
        if (!reader.writeSlot(slot, b4, b5)) {
          st = "WRITE " + String(trayDisplayNo(slot)) + " no card";
        } else {
          slotKey[slot] = type + "|" + color;
          stableCount[slot] = STABLE_COUNT;
          pushPending[slot] = true;  // 后台 loop 推，slotSent 留给后台记
          st = "WRITE " + String(trayDisplayNo(slot)) + " pushing";
          ok = true;  // 卡已写上，推送中也算写卡成功
        }
      }
    }
  }
  statusText = st;
  shownKey = "";  // 强制刷屏（老屏直刷；MiaoUI 状态行下轮喂数同步）
  logLine(st);
  return ok;
}

// 屏上 Write 结果查询：供 Fbx_WriteCard 弹结果提示（返回 statusText 快照，调用方立即拷贝）
const char* fbxLastWriteMsg() { return statusText.c_str(); }

void setup() {
  Serial.begin(115200);
  logLine("[BOOT] start");
  reader.begin();
  logLine("[BOOT] reader ok");
  ledBegin();  // GPIO2 strapping 安全点：reader 之后再 ledBegin 即安全
  ledSet(LED_WIFI_CONNECT);

  // OLED 先初始化，后续 WiFi 连接/配网状态全程显示在屏上
  ui.begin();
  // MiaoUI 接管正常态显示；失败/无屏回落老直刷屏（配网阻塞段始终用老屏）
  if (ui.ok()) {
    bool miaoUp = miaouiSetupMenu();
    logLine("[MIAOUI] " + String(miaoUp ? "active" : "fallback") +
            " free=" + String((unsigned)ESP.getFreeHeap()));
  }

  // 打印机配置：NVS 优先，config.h 保底
  loadPrinterCfg(gPrinter);
  logLine("[BOOT] printer cfg ok");

  // 无网络自动开 AP 配网（阻塞直到配网成功重启；OLED 显示进度）
  ensureWifiOrPortal(&ui);
  logLine("[BOOT] wifi ok");
  ledSet(LED_HEARTBEAT);  // 联网成功回心跳

  // 开机 IP 页（仅老屏回落时显示；MiaoUI 接管时 IP 在 System>IP 菜单里看）
  if (ui.ok() && !miaouiActive()) {
    String splash[5] = {
      "WiFi OK",
      WiFi.localIP().toString(),
      "/setup",
      "to homepage...",
      ""
    };
    ui.showLines(splash, 5);
    logLine("[BOOT] ip " + WiFi.localIP().toString());
    for (uint16_t w = 0; w < OLED_IP_SPLASH_MS; w += 50) { ledTick(); delay(50); }
    shownKey = "";  // 强制重刷主页
  } else if (ui.ok()) {
    logLine("[BOOT] ip " + WiFi.localIP().toString());
  }

  // WiFi 连上之后再起常驻 Web 服务（管理首页 / + 写卡 /write + 配置 /setup）
  startPrinterSetup(gPrinter);
  WebServer& web = setupWebServer();
  web.on("/", handleDashRoot);
  web.on("/write", HTTP_GET, handleDashWriteForm);
  web.on("/write", HTTP_POST, handleDashWrite);
  web.on("/log", handleDashLog);
  web.on("/log/stream", handleDashLogStream);
  web.on("/log.txt", handleDashLogText);
  web.on("/log/clear", HTTP_POST, handleDashLogClear);
  logLine("[BOOT] setup server ok");

  statusText = "idle";
  refreshOled();
  logLine("FilamentBox ready");
}

void loop() {
  ledTick();
  // 运行中掉线：OLED 显示重连状态；超 2 分钟连不上则重启（重启后自动进配网）
  if (WiFi.status() != WL_CONNECTED) {
    ledSet(LED_WIFI_CONNECT);
    ledTick();
    if (wifiDownSince == 0) {
      wifiDownSince = millis();
      WiFi.disconnect();
      WiFi.mode(WIFI_STA);
      WiFi.begin();  // 用上次凭据（NVS/默认）重连
    }
    statusText = "WiFi retry";
    refreshOled();
    if (millis() - wifiDownSince > WIFI_DOWN_REBOOT_MS) ESP.restart();
    waitPollWindow();
    return;
  }
  if (wifiDownSince != 0) {
    // 刚恢复连接：状态回 idle 并强制重刷一屏
    wifiDownSince = 0;
    statusText = "idle";
    shownKey = "";
    if (!printerHintShown) ledSet(LED_HEARTBEAT);
  }
  printerSetupHandle();  // 常驻 /setup 配置页请求处理

  // 轮询只置脏不推送：同槽连续换卡时 slotKey 天然只留最新，旧值直接被覆盖丢弃。
  for (uint8_t i = 0; i < NUM_SLOTS; i++) {
    uint8_t b4[16], b5[16];
    String key = "";
    if (reader.readSlot(i, b4, b5)) {
      String t, c;
      if (decodeCard(b4, b5, t, c) && checkColor(c) && lookupFilament(t)) {
        key = t + "|" + c;
      }
    }
    if (key == slotKey[i]) {
      if (stableCount[i] < 255) stableCount[i]++;
    } else {
      stableCount[i] = 0;
      slotKey[i] = key;
    }
    if (key.length() == 0) {
      // 拔卡：清已发送标记 + 取消本槽待推。失败曾记 slotSent=key 抑制自动重试，
      // 此处清掉后，手动重插同卡时 key != slotSent 成立，可再推一次。
      slotSent[i] = "";
      pushPending[i] = false;
      continue;
    }
    if (stableCount[i] >= STABLE_COUNT && key != slotSent[i]) {
      pushPending[i] = true;
    }
    printerSetupHandle();  // 逐槽间隙处理 Web，4 槽轮询期请求也能响应
  }

  // 后台推送：每轮最多一槽（轮转防饿死）。推前用 slotKey 最新值组包，
  // 同槽在轮询期被覆盖的旧值不会再推；失败也记 slotSent=key（不自动重试）。
  for (uint8_t n = 0; n < NUM_SLOTS; n++) {
    uint8_t i = (uint8_t)((pushCursor + n) % NUM_SLOTS);
    if (!pushPending[i]) continue;
    pushCursor = (uint8_t)((i + 1) % NUM_SLOTS);
    pushPending[i] = false;
    if (slotKey[i].length() == 0) { slotSent[i] = ""; break; }  // 推前复核：卡已拔则丢弃
    printerSetupHandle();  // 推送前让 Web 先回一次
    String err;
    String key = slotKey[i];  // 快照：判脏用（单线程推送期无并发改写，纯防御）
    if (pushSlotNow(i, err)) {
      if (slotKey[i] == key) slotSent[i] = key;
      else slotSent[i] = slotKey[i];  // 推送期被写卡覆盖：旧结果丢弃，记最新为已发由下轮复核
      if (slotKey[i] != key) pushPending[i] = true;  // 覆盖发生时补推最新
    } else {
      if (slotKey[i] == key) slotSent[i] = key;  // 失败抑制自动重试，拔卡清标记后重插可再推
    }
    printerSetupHandle();  // 推送后立刻处理 Web
    break;  // 一轮一槽，剩余脏槽下轮继续
  }

  refreshOled();
  waitPollWindow();
}

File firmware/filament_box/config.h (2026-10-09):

#pragma once
// config.h — FilamentBox 唯一配置入口（ESP32 30针 DevKit，Arduino 方式）

// ---- WiFi ----
// 出厂默认值；一旦用 AP 配网成功，凭据存 NVS，开机优先用 NVS 的，改这里不再生效
// （要换 WiFi：删 NVS 让设备重进配网，或重新配一次即可）
#define WIFI_SSID "your-ssid"
#define WIFI_PASS "your-pass"

// ---- 拓竹打印机（局域网模式）----
// 出厂默认值；一旦在 /setup 页保存成功，以 NVS 为准，改这里不再生效
#define PRINTER_IP "192.168.1.100"   // 打印机屏幕 / 路由器里查
#define PRINTER_SERIAL "00M00A000000000"
#define PRINTER_ACCESS_CODE "12345678"  // 打印机屏幕 -> 设置 -> 局域网访问码
#define AMS_ID 0

// ---- 轮询 ----
#define POLL_MS 800        // 主循环间隔（毫秒）
#define STABLE_COUNT 2     // 连续读到相同才算有效（去抖）

// ---- VSPI 总线（4 路 RC522 共用）----
#define SPI_SCK_PIN 18
#define SPI_MOSI_PIN 23
#define SPI_MISO_PIN 19
#define RC522_RST_PIN 27   // 4 路共用 RST

// ---- 4 个槽位：tray_id 对应 AMS Lite 0-3（协议层，只能是 0-3），CS 独立（空闲高电平的安全脚）----
#define NUM_SLOTS 4
static const uint8_t SLOT_CS[NUM_SLOTS] = {5, 4, 13, 14};
static const uint8_t SLOT_TRAY[NUM_SLOTS] = {0, 1, 2, 3};
// 显示用槽号：用户界面一律从 1 开始（1-4，与 Bambu Studio 对齐）；
// 协议层（MQTT tray_id）仍用 SLOT_TRAY 的 0-3，两处不可混用
inline uint8_t trayDisplayNo(uint8_t i) { return (uint8_t)(SLOT_TRAY[i] + 1); }

// ---- SSD1306 OLED（硬件 I2C）----
#define OLED_SDA_PIN 21
#define OLED_SCL_PIN 22
#define OLED_ADDR 0x3C
// 顶部死区：屏幕上边坏掉的像素行数，坏区一个像素都不用（健康屏 0；坏顶屏改回 10，
// 同时把 miaoui/ui_conf.h 的 UI_PAGE_INIT_Y 改为 UI_FONT_HIGHT + 10）
#define OLED_TOP_DEAD 0
// 开机 IP 页停留毫秒数（WiFi 连上后显示本机 IP，然后自动切主页）
#define OLED_IP_SPLASH_MS 3000

// ---- 按键（输入上拉，接地为按下；MiaoUI 三键：上/下/确认）----
#define BUTTON_PIN 33       // 确认键（菜单确认 / 执行）
#define BTN_UP_PIN 32       // MiaoUI 上键（新增，接 GND）
#define BTN_DOWN_PIN 25     // MiaoUI 下键（新增，接 GND）
#define BTN_ENTER_PIN BUTTON_PIN  // MiaoUI 确认键复用旧按键

// ---- 板载状态灯（D2 = GPIO2 板载蓝灯，高电平亮）----
// GPIO2 是 strapping 脚：setup() 之前不驱动，reader.begin() 之后再 ledBegin() 即安全
#define LED_PIN 2
#define LED_ACTIVE_HIGH 1

// ---- 写卡 AP ----
#define SETUP_AP_SSID "FilamentBox-SETUP"

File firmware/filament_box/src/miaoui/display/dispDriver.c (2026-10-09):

/*
 * This file is part of the MiaoUI Library.
 *
 * Copyright (c) 2025, JFeng-Z, <2834294740@qq.com>
 *
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
 * Created on: 2025-02-08
 */
#include "dispDriver.h"
#include "../hal/fbx_display.h"

/**
 * 初始化显示设备。
 * 该函数负责初始化OLED显示器，并设置默认字体。
 * 
 * @无参数
 * @无返回值
 */
void dispInit(void)
{
    // 初始化U8g2库，为OLED显示做准备
    HAL_dispInit( );
}

/**
 * 清除OLED显示缓冲区
 * 
 * 该函数用于清空OLED显示器的缓冲区，为新的显示内容做准备。
 * 
 * 参数: 
 * 无
 * 
 * 返回值: 
 * 无
 */
void Disp_ClearBuffer(void)
{
    HAL_Disp_ClearBuffer( ); // 清除OLED显示缓冲区的具体实现，使用u8g2库提供的函数。
}

/**
 * 向OLED发送缓冲区数据
 * 该函数无参数。
 * 该函数无返回值。
 */
void Disp_SendBuffer(void)
{
    /* 将U8G2实例的缓冲区数据发送到OLED设备 */
    HAL_Disp_SendBuffer( );
}

/**
 * 设置OLED显示器的字体。
 * 
 * @param font 指向要使用的字体的指针。该字体必须是提前定义并可用的。
 * 
 * 说明：这个函数通过调用u8g2的设置函数，来更改当前OLED显示的字体。
 */
void Disp_SetFont(const uint8_t *font)
{
    HAL_Disp_SetFont(font);
}

/**
 * 在OLED显示器上绘制一条线。
 * 
 * @param x1 起始点的X坐标。
 * @param y1 起始点的Y坐标。
 * @param x2 终点的X坐标。
 * @param y2 终点的Y坐标。
 * 
 * 该函数调用u8g2的DrawLine函数，使用给定的起始点和终点坐标在OLED显示器上绘制一条线。
 */
void Disp_DrawLine(uint16_t x1, uint16_t y1, uint16_t x2, uint16_t y2)
{
    HAL_Disp_DrawLine(x1, y1, x2, y2);
}

/**
 * 在OLED屏幕上绘制字符串
 * 
 * @param x 字符串起始绘制的x坐标
 * @param y 字符串起始绘制的y坐标
 * @param str 要绘制的字符串
 * @return 绘制后的光标位置（一般为字符串的结束位置），具体返回值意义可能依赖于u8g2库的实现
 */
uint16_t Disp_DrawStr(uint16_t x, uint16_t y, const char *str)
{
    // 调用u8g2库的DrawStr函数，在指定位置绘制字符串
    return HAL_Disp_DrawStr(x, y, str);
}

/**
 * 设置OLED显示设备的绘制颜色。
 * 
 * @param color 指定的绘制颜色，使用uint8_t类型表示。颜色的具体编码取决于OLED驱动库的实现。
 * 
 * 该函数通过调用u8g2库的u8g2_SetDrawColor函数，来设置当前绘制的颜色。绘制颜色会影响后续所有绘制操作。
 */
void Disp_SetDrawColor(void *color)
{
    HAL_Disp_SetDrawColor(color);
}

/**
 * 在OLED屏幕上绘制一个框架。
 * 
 * @param x 框架的起始x坐标。
 * @param y 框架的起始y坐标。
 * @param w 框架的宽度。
 * @param h 框架的高度。
 * 
 * 该函数调用u8g2的绘制框架函数，用于在指定位置和尺寸上绘制一个框架。
 */
void Disp_DrawFrame(uint16_t x, uint16_t y, uint16_t w, uint16_t h)
{
    HAL_Disp_DrawFrame(x, y, w, h);
}

/**
 * 在OLED屏幕上绘制一个矩形边框。
 * 
 * @param x 矩形左上角x坐标。
 * @param y 矩形左上角y坐标。
 * @param w 矩形的宽度。
 * @param h 矩形的高度。
 * @param r 矩形圆角的半径。
 * 
 * 该函数调用u8g2的绘制函数，用于在指定位置以指定尺寸和圆角半径绘制一个矩形边框。
 */
void Disp_DrawRFrame(uint16_t x, uint16_t y, uint16_t w, uint16_t h, uint16_t r)
{
    HAL_Disp_DrawRFrame(x, y, w, h, r);
}

/**
 * 在OLED显示器上绘制一个矩形框。
 * 
 * @param x 矩形框左上角的x坐标。
 * @param y 矩形框左上角的y坐标。
 * @param w 矩形框的宽度。
 * @param h 矩形框的高度。
 * 
 * 该函数调用u8g2的绘制矩形框函数，传入指定的坐标和尺寸，在OLED屏幕上绘制矩形。
 */
void Disp_DrawBox(uint16_t x, uint16_t y, uint16_t w, uint16_t h)
{
    HAL_Disp_DrawBox(x, y, w, h);
}

/**
 * 在OLED显示器上绘制一个带圆角的矩形。
 * 
 * @param x 矩形左上角的x坐标。
 * @param y 矩形左上角的y坐标。
 * @param w 矩形的宽度。
 * @param h 矩形的高度。
 * @param r 矩形圆角的半径。
 * 
 * 该函数调用u8g2的绘制函数，以指定的坐标和尺寸，在OLED显示器上绘制一个带圆角的矩形。
 */
void Disp_DrawRBox(uint16_t x, uint16_t y, uint16_t w, uint16_t h, uint16_t r)
{
    HAL_Disp_DrawRBox(x, y, w, h, r);
}

/**
 * 在OLED显示器上绘制一个XBM图像。
 * 
 * @param x 图像在显示器上的起始x坐标。
 * @param y 图像在显示器上的起始y坐标。
 * @param w 图像的宽度。
 * @param h 图像的高度。
 * @param bitmap 指向包含XBM图像数据的缓冲区的指针。
 * 
 * 此函数使用u8g2库的u8g2_DrawXBMP函数来绘制图像。图像数据必须是XBM格式的。
 */
void Disp_DrawXBMP(uint16_t x, uint16_t y, uint16_t w, uint16_t h, const uint8_t *bitmap)
{
    HAL_Disp_DrawXBMP(x, y, w, h, bitmap);
}

/**
 * 设置OLED显示器的对比度。
 * 
 * @param value 对比度值，有效范围通常为0到255，具体取决于硬件的限制。
 * 
 * 该函数通过调用u8g2库中的u8g2_SetContrast函数，来设置OLED显示器的对比度。
 * 使用者需要根据具体的OLED显示器和u8g2配置来选择合适的对比度值。
 */
void Disp_SetContrast(ui_t *ui)
{
    HAL_Disp_SetContrast(ui);
}

/**
 * 设置OLED电源节省模式
 * 
 * 本函数用于根据输入参数启用或禁用OLED的电源节省模式。当is_enable为1时，启用电源节省模式；
 * 当is_enable为0时，禁用电源节省模式。
 * 
 * @param is_enable 一个无符号字符(uint8_t)，用来控制是否启用电源节省模式。
 *                  当其值为1时，启用电源节省模式；当其值为0时，禁用电源节省模式。
 */
void Disp_SetPowerSave(ui_t *ui)
{
    HAL_Disp_SetPowerSave(ui);
}

/**
 * 获取OLED缓冲区的 tile 高度。
 * 
 * 该函数不接受参数。
 * 
 * @return 返回OLED缓冲区的tile高度。返回值为uint8_t类型，即无符号8位整数。
 */
uint8_t Disp_GetBufferTileHeight(void)
{
    return HAL_Disp_GetBufferTileHeight( );
}

/**
 * 获取OLED缓冲区的单个瓦片宽度。
 * 
 * 该函数查询U8G2图形库当前配置的OLED缓冲区的单个瓦片宽度。瓦片宽度是指OLED屏幕
 * 在显示更新时，一次可以处理的像素宽度。这个值通常取决于OLED屏幕的物理分辨率
 * 和U8G2库的内部处理方式。
 * 
 * @return 返回OLED缓冲区单个瓦片的宽度，单位为字节。
 */
uint8_t Disp_GetBufferTileWidth(void)
{
    return HAL_Disp_GetBufferTileWidth( );
}

/**
 * 获取OLED显示缓冲区的指针
 * 
 * 该函数用于获取当前OLED显示设备的显示缓冲区的指针。该缓冲区是一个uint8_t类型的数组，
 * 用于存储即将显示在OLED屏幕上的图像数据。
 * 
 * @return 返回类型为uint8_t*，指向OLED显示缓冲区的起始位置。
 */
uint8_t *Disp_GetBufferPtr(void)
{
    // 调用u8g2库的函数获取显示缓冲区指针
    return HAL_Disp_GetBufferPtr( );
}

void Disp_SetClipWindow(uint16_t clip_x0, uint16_t clip_y0, uint16_t clip_x1, uint16_t clip_y1)
{
    HAL_Disp_SetClipWindow(clip_x0, clip_y0, clip_x1, clip_y1);
}

void Disp_SetMaxClipWindow(void)
{
    HAL_Disp_SetMaxClipWindow( );
}

void Disp_SetBufferCurrTileRow(uint8_t row)
{
    HAL_Disp_SetBufferCurrTileRow(row);
}

uint16_t Disp_DrawUTF8(uint16_t x, uint16_t y, const char *str)
{
    return HAL_Disp_DrawUTF8(x, y, str);
}

uint16_t Disp_GetUTF8Width(const char *str)
{
    return HAL_Disp_GetUTF8Width(str);
}

void Disp_UpdateDisplayArea(uint8_t tx, uint8_t ty, uint8_t tw, uint8_t th)
{
    HAL_Disp_UpdateDisplayArea(tx, ty, tw, th);
}

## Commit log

2026-09-14 FilamentBox 初版提交：ESP32 RFID 耗材识别 + AMS Lite 推送 + 网页后台
2026-09-14 更新 .gitignore 文件，添加 .opencode 目录以避免本地工具配置被跟踪
2026-09-14 添加状态灯功能，优化 WiFi 连接和写卡模式的指示灯逻辑；更新 README 文档以反映更改
    [ESP32 OLED Mag Case Lid.stl, ESP32_OLED_Magnetic_Case.stl, RFID Lid.stl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]
2026-09-18 Add initial Blender model files
    - Created new Blender model file: 模型\源.blend
    - Created backup Blender model file: 模型\源.blend1
    [INSERT6L8.stl, NFC-Filament-Swatch.stl, PIN6L8.stl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]
2026-10-09 提交初版
    [nfc卡.stl, 上部上盖.stl, 底座.3mf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]
